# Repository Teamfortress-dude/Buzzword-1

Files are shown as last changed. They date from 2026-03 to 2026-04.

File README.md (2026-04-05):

# Buzzword-1 (NOT UPDATED, WILL UPDATE ONCE PROJECT IS FINISHED)

**What is it?**
-
The first model rocket I have ever made. It is a model rocket capable of reaching a max altitude of 400+ meters. It uses a custom G112 motor designed using OnShape and other simulation softwares and uses KNSB as propellant. It uses a CO2 ejection system. My goal with this project is to popularize model rocketry in Indonesia because currently, model rocketry is almost non-existant.

**How it roughly works**
-
1. Cook KNSB rocket propellant and cast it into PET-CF molds.
2. Create liner out of kraft paper and load in the grains each with a 2mm kraft paper separator in between each grain.
3. Load into tail end section of rocket and secure using fastening plate.
4. Set spring in CO2 piercer and load cartridge (ensure servo is powered during this process).
5. Place CO2 ejector in the upper section and load the shock cord and parachute.
6. Place rocket on launch pad (ensure the launch rod is going through the launch lug).
7. Insert igniter inside motor.
8. Stand back a minimum of 15 meters.
9. Launch.

**How the firmware roughly works**
-
I'm not 100% sure how it works either as (I'm going to be completely honest) I used AI to assist me in the creation of it, but I can tell you how to use it.

Igniter: 

1. Connect to the ESP32 DevKit v1 via bluetooth.
2. Here you can send it the required commands through the serial monitor.

Ejection System:

1. Have the ESP32-C3 Super Mini connected to your laptop via USB to lock the spring in place.
2. Ensure you are connected to the igniter as the only way to arm the system is through there.
3. Everything else is completely automatic.

**Why I made it** 
-
Ever since I was 5 years old, I have always been very interested in aviation. I began learning about different aircraft at the age of 7, and it soon became a hobby of mine to study various planes. This eventually led me to playing Kerbal Space Program, where I designed various types of jet-powered aircraft. After about a month of playing (when I was around 13 years old), I tried to build my first rocket to orbit Kerbin (KSP's version of Earth). That was when I began to get fascinated with rockets. However, it wasn't until I was 15 that I started seriously learning about rocket mechanics, the history of rocketry, and large-scale rockets.

I wanted to make a small scale model rocket but I soon realised just how unpopular model rocketry is in Indonesia, with small A class motors that usually cost 1-5$ in Canada costing over 90$ here. It was here where I decided I was going to build everything from scratch, including the motor. When I was about halfway through in just motor designing, I realised just how much this project was going to cost so I retired the project early. It was only when I discovered the Blueprint program that I immediately fired up the project again.

**CAD**
-
**Buzzword-1 Rocket Body** OnShape: https://cad.onshape.com/documents/6395d56e8419870e36c364c0/w/89d10f0ab768237c661b4cfe/e/bca3e17cd6460ee306ad322d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

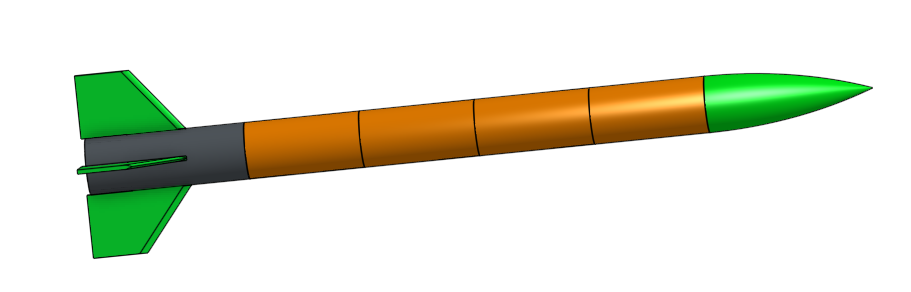
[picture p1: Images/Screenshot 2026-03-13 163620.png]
Rocket


**G112 EX Rocket Motor** OnShape: https://cad.onshape.com/documents/9d5704bc2d8bf989355a524c/w/8b6d99253b12667f572559fd/e/144e5694a96a8de6b9af8a30

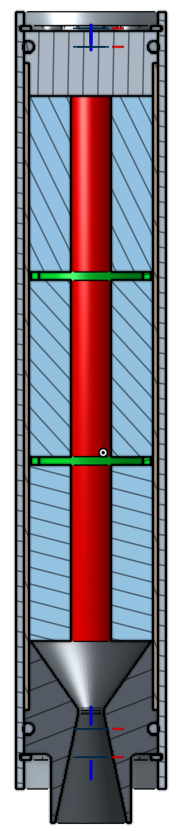
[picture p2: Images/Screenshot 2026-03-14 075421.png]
Motor


**CO2 Ejection System Frame** OnShape: https://cad.onshape.com/documents/45ce68cde51d3e3fd76b4ad7/w/09d733e07eaebf7fc37995c2/e/72d23b56d11aaa349a665c4d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

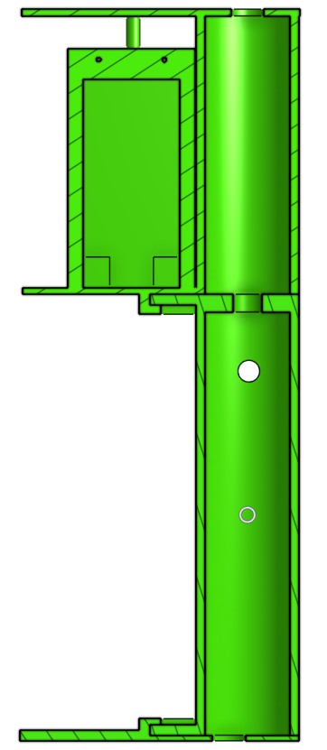
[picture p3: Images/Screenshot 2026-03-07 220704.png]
CO2


**Launch Pad Frame** OnShape: https://cad.onshape.com/documents/3f7ec817d1382ceb388e982a/w/608521341a8481e5177d8379/e/9c587c68358a26500574c930

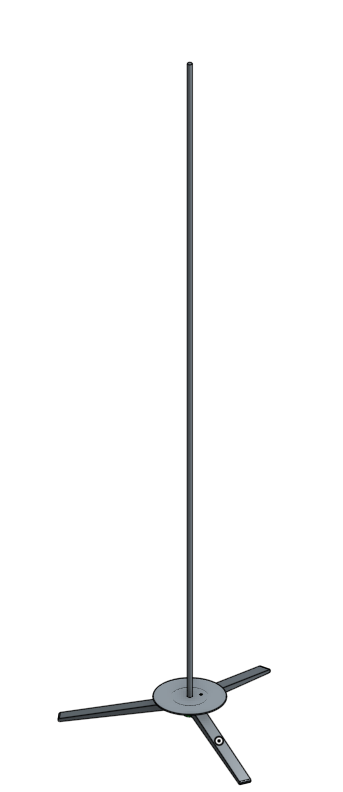
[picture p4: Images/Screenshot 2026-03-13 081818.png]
Launch


**Wireless Igniter** OnShape: https://cad.onshape.com/documents/17522f05e2172b3d15a9535d/w/4dee14af77d33351ef336225/e/4c8c179b079365a7d7b485c3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

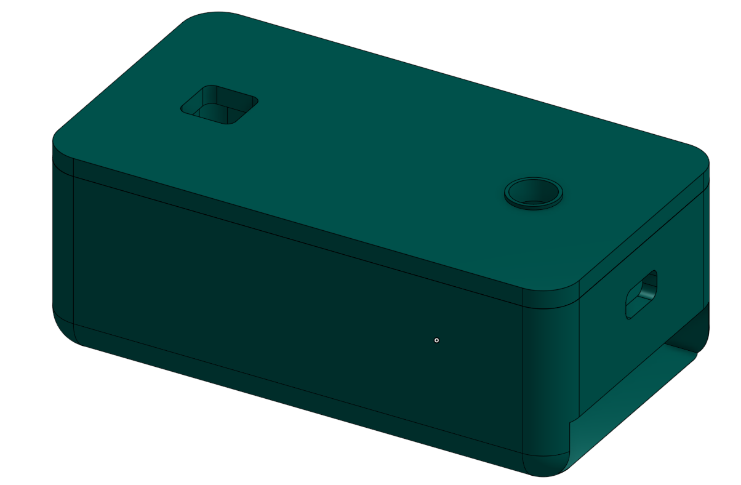
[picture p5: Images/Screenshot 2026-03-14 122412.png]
Igniter


**KNSB Mold** OnShape: https://cad.onshape.com/documents/3a6b5b3d99b7bc82c2f6d8e7/w/60bf61435858e4b373d2f9f6/e/a12e0d0e7426bf0f7a0a3a54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

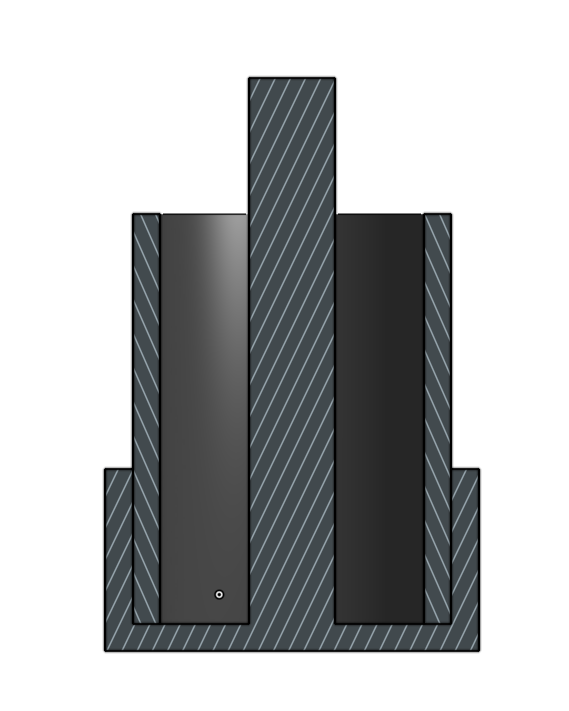
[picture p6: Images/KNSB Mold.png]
Mold


**Wiring Diagrams**
-
**CO2 Ejection System Wiring Diagram**

Ejection System_schem

**Wireless Igniter Wiring Diagram**

Igniter_schem

# Buzzword-1 Rocket BOM

(Prices converted from IDR to USD as of March 15, 2026)

Docs Link: https://docs.google.com/spreadsheets/d/1oULfb8y-ewKrFI3QsoMtwvTD6bKZGtqLrj3OP-NL9gE/edit?usp=sharing

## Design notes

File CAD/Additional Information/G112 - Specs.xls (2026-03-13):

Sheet: Intro
SRM 2023.XLS | Written by: | Richard A.Nakka
Solid Rocket Motor Performance | Version: | 2023 (for free distribution). Supercedes SRM_2014.XLS version 1.1 (2014)
 | Date: | 2023-03-23
Instructions for use: Enter required data in the blue-outlined cells (with blue text)
Note that some data cells have drop-down lists
Then click on the Solve buttons (1-3)
Introduction
Changes incorporated into SRM 2023 version
KNPSB and KNFR have been added to the choice of propellants. All propellant properties have been
tweaked based on revised two-phase flow analysis. The value of "k" is corrected to a single value. The
overall effect of these updated property values is a small reduction in predicted performance (thrust, total
impulse & specific impulse) compared to SRM_2014. Motor performance up to "V" class is now supported.
This spreadsheet was created in order to predict the performance of a Solid Rocket
Motor (SRM). Although there are many factors which make a precise prediction
of actual performance difficult, it was felt that a reasonably close approximation
to expected performance would be attainable, and be very useful for design purposes.
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

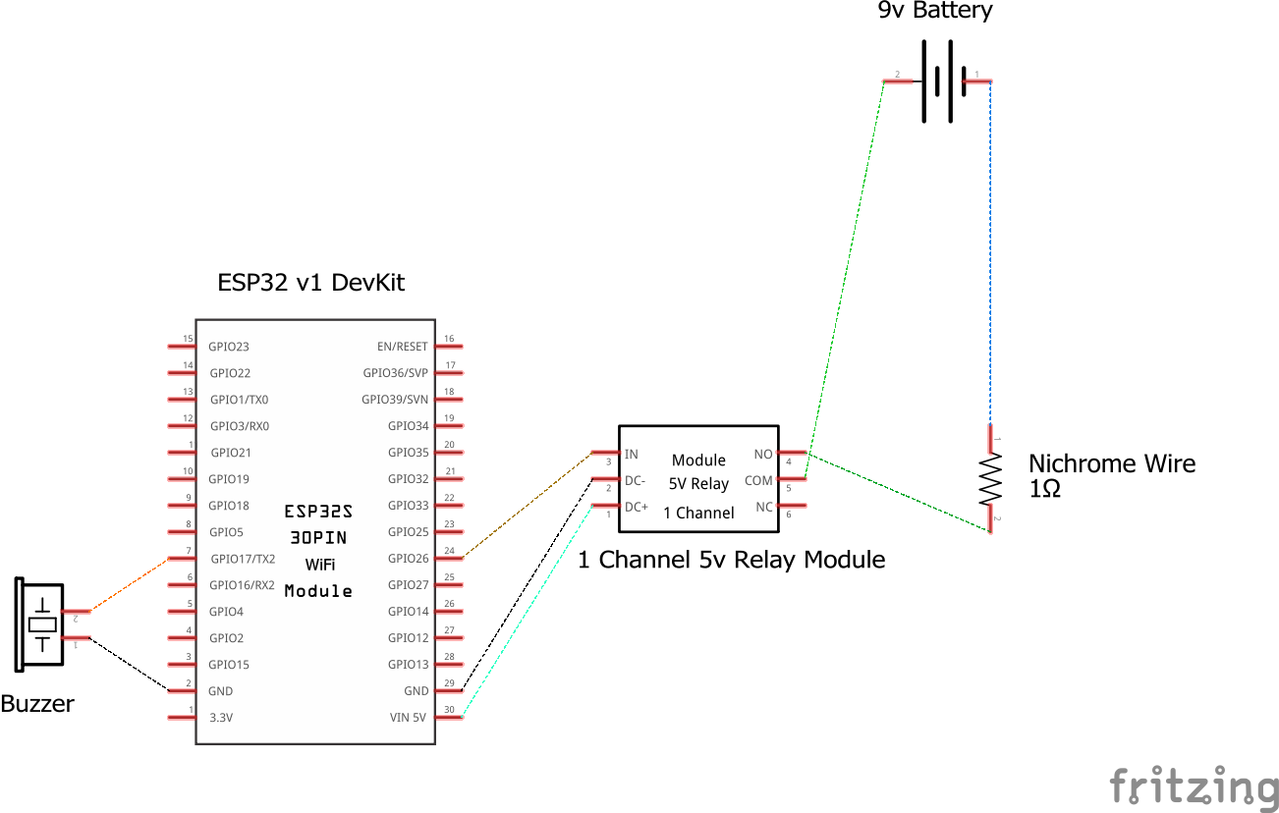
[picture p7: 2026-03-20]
Images/Igniter_schem.png

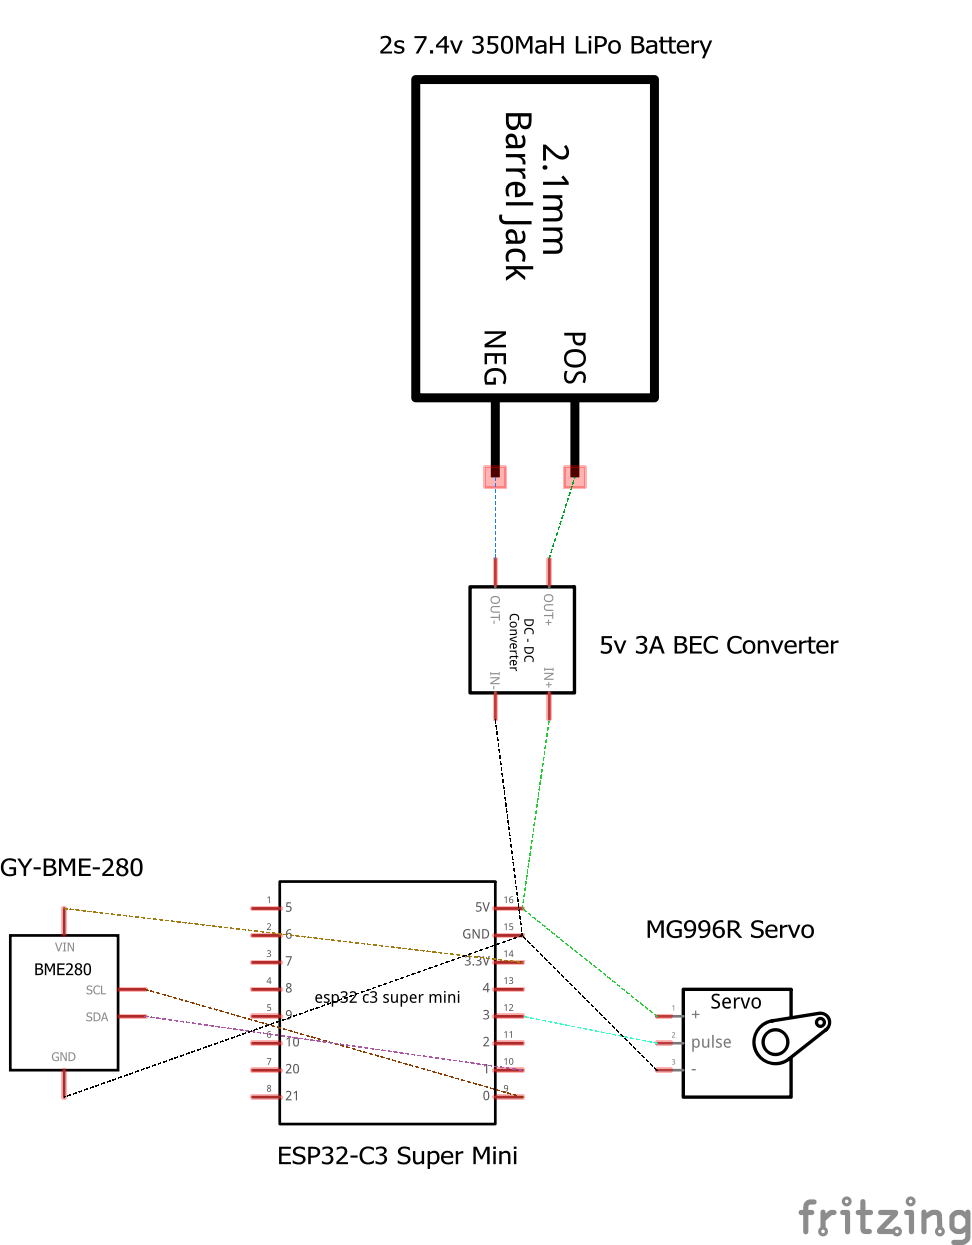
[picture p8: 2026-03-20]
Images/Ejection System_schem.png

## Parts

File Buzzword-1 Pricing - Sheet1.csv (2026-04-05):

G112 Rocket Motor
Item | Description | Quantity | Unit Price | Total Price | Links
Nozzle | CNC nozzle made of 304 stainless steel | 1 | $64.33 | $64.33 | https://drive.google.com/file/d/1FW6xyB7vkZJ01Jm_9k6G-RV7ilLzCY_d/view?usp=sharing
Casing | CNC casing made of 6061 aluminium | 1 | $70.01 | $70.01 | https://drive.google.com/file/d/1gcDKhTj_kWKR1uE6eL6LAUmwJq2hkqq-/view?usp=sharing
Bulkhead | CNC bulkhead made 6061 aluminium | 1 | $19.73 | $19.73 | https://drive.google.com/file/d/1FW6xyB7vkZJ01Jm_9k6G-RV7ilLzCY_d/view?usp=sharing
CNC Shipping 1 | Shipping cost | 1 | $17.00 | $17.00 | https://drive.google.com/file/d/1FW6xyB7vkZJ01Jm_9k6G-RV7ilLzCY_d/view?usp=sharing
CNC Shipping 2 | Secondary shipping cost due misinput on one of the items. | 1 | $1.50 | $1.50 | https://drive.google.com/file/d/1gcDKhTj_kWKR1uE6eL6LAUmwJq2hkqq-/view?usp=sharing
-120 O-ring | O-ring used for sealing gases in casing | 20 | $0.09 | $1.80 | https://www.tokopedia.com/ichibanseal/oring-as-120-25-0x2-62-id-25-0-mm-x-tebal-2-62-mm-nbr-1731112036310419029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
-121 O-ring | O-ring used for sealing gases in casing | 20 | $0.09 | $1.80 | https://www.tokopedia.com/ichibanseal/oring-as-121-26-6x2-62-id-26-6-mm-x-tebal-2-62-mm-nbr
H31 Snap ring | Snap rings used to hold nozzle and bulkhead in place | 2 | $1.88 | $3.76 | https://www.tokopedia.com/ray-fasteners/ss304-snap-ring-stainless-h31-internal-circlip-snapring-type-h-31mm
310 gsm kraft paper | Used as a thermal liner between the propellant and casing | 1 | $0.88 | $0.88 | https://www.tokopedia.com/kraftboss/kertas-kraft-liner-samson-brown-kraft-coklat-uk-a4-paket-isi-50-termurah-paper-1730794130547835917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
1kg sorbitol | Used as the fuel of the rocket motor | 1 | $6.03 | $6.03 | https://www.tokopedia.com/putrapanganprima/pemanis-sorbitol-bubuk-powder-serbuk-food-grade-100gr-250gr-500gr-1kg-1-kg-d9cf3
1kg potassium nitrate | Used as the oxidiser of the rocket motor | 1 | $3.25 | $3.25 | https://www.tokopedia.com/cocoingid/pupuk-potassium-nitrate-kno3-kingenta-repack-1-kg-80056
1 kg iron oxide | Used as a catalyst in the propellant | 1 | $2.08 | $2.08 | https://www.tokopedia.com/niochemical/iron-oxide-red-merah-1kg-1731250527442601696
Wood glue | Used to make the liner, motor mount, and grain inhibitor | 1 | $2.07 | $2.07 | https://www.tokopedia.com/aqualuxeid/aqualuxe-woodglue-lem-kayu-pvac-1kg-putih-super-kuat-cepat-kering-untuk-plamir-tembok-kertas-waterproof-dan-invisible-172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
PET-CF Filament | Used to make KNSB molds and for any high heat resistant parts | 1 | $24.75 | $24.75 | https://www.tokopedia.com/indocart/3d-printer-filament-polymaker-fiberon-pet-cf17-carbon-fiber-reinforced-pet-filament-1-75mm-500gr-1731307743431722527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
200 gsm kraft paper | Used as a grain inhibitor | 1 | $0.53 | $0.53 | https://www.tokopedia.com/kraftboss/kertas-kraft-liner-samson-brown-kraft-coklat-uk-a4-paket-isi-50-termurah-paper-1730794130547704845
Silicone grease | Used to seal the o-ring | 2 | $0.56 | $1.12 | https://www.tokopedia.com/alesya-market-store/anoso-pelumas-o-ring-grade-silicon-grease-lubricant-10g-sgl6502
 |  |  | Total Cost: | $220.64
CO2 Recovery System
Item | Description | Quantity | Unit Price | Total Price | Links
CO2 Cartridges | Used as the rapid expanding gas | 2 | $2.77 | $5.54 | https://www.tokopedia.com/esgtactical/co2-pompa-sepeda-usa-gold-gamo-original-1-kotak-isi-5pcs-12gr-1734388919894246627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
ESP32-C3 Super Mini | The microcontroller used to activate a servo at a specific altitude | 1 | $2.96 | $2.96 | https://www.tokopedia.com/ichibot/esp32-c3-supermini-development-board-dengan-wifi-dan-bluetooth-built-in-4m-flash-memory-esp32-belum-tersolder
GY-BMP-280 | A barometer module use as an altimeter for the ESP32 | 1 | $0.66 | $0.66 | https://www.tokopedia.com/solarperfect/gy-bmp280-3-3-high-precision-atmospheric-pressure-sensor-module-gy-280
24 AWG Silicone Wire | Used as the connectors between the 5V BEC and ESP32 and MG996R servo | 1 | $0.12 | $0.12 | https://www.tokopedia.com/dielectronics/24-awg-high-quality-silicone-wire-cable-kabel-silikon-serabut-putih-biru
28 AWG Wire | Used as the connector between the ESP32 and GY-BMP-280 | 1 | $0.12 | $0.12 | https://www.tokopedia.com/cncstorebandung/kabel-serabut-awg-28-awg28-high-quality-hitam
5V 3A BEC Converter | A converter between the 7.6v 2S LiPo battery and components | 1 | $1.90 | $1.90 | https://www.tokopedia.com/alladinshop/bluesky-3a-5v-ubec-bec-vdc-dc-converter-step-down-module-mini-fpv
350 MaH 2S LiPo Battery | Used as the main power source for on board avionics | 1 | $4.24 | $4.24 | https://www.tokopedia.com/justshopit/cnhl-lihv-ministar-hv-350mah-7-6v-2s-70c-lipo-battery-xt30
XT30 Plug connector | Allows the battery to plug into the BEC converter | 1 | $0.53 | $0.53 | https://www.tokopedia.com/justshopit/amass-xt30-xt30u-plug-connector-female-male-lipo-battery-for-rc-fpv-drone-1729895395040659171
Heat shrink wire covers set | Allow for cleaner and sturdier connections | 1 | $0.65 | $0.65 | https://www.tokopedia.com/skf88/heat-shrink-kabel-164-530pcs-isolasi-bakar-tube-selang-bakar-bahan-polyolefin-warna-warni-1732990049052886837
 |  |  | Total Cost: | $16.72
Rocket Body Construction
Item | Description | Quantity | Unit Price | Total Price | Links
Parachute | Will be used as the recovery system | 1 | $1.72 | $1.72 | https://www.tokopedia.com/penny-y/2pcs-mainan-parasut-anak-mainan-anak-terjun-payung-terjun-payung-mainan-payung-terjun-merah-2pcs-6cad4
Sandpaper | Used to smooth out the rocket body | 2 | $0.51 | $1.02 | https://www.tokopedia.com/ud-33/paket-amplas-auto-kinclong-duco-lembar-320-2000-3000-1dfe8?t_id=1774713139184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
4mm Paracord per meter | Used as a shock cord connecting the nose to the rocket body during recovery | 4 | $0.71 | $2.84 | https://www.tokopedia.com/acckingdom47/genuine-tali-paracord-550-4mm-asli-premium-kuat-motif-multicolor-uv-resistant-anti-pudar-survival-cord-serbaguna-gunung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
 |  |  | Total Cost: | $5.58
Launchpad and Igniter
Item | Description | Quantity | Unit Price | Total Price | Links
15 cm Stainless steel disk | Used for redicrecting the hot exhaust gas during launch | 1 | $1.48 | $1.48 | https://www.tokopedia.com/ajm175/plat-bulat-stainless-1-2-mm-uk-5-20-cm-1731311695462827268
155cm Stainless steel rod | Used as the launch rod to guide the rocket during takeoff | 1 | $7.75 | $7.75 | https://www.tokopedia.com/rajawali3d/smooth-rod-stainless-steel-304-10mm-per-cm-linear-shaft-rail
ESP32 DevKit v1 | Used for wireless ignition | 1 | $5.08 | $5.08 | https://www.tokopedia.com/cncstorebandung/esp32-esp-32s-doit-cp2102-type-c-38-pin-board-wifi-bluetooth-iot-dual-core-proyek-elektronik-1731127910335219262
9v Battery | Used to power ignition | 4 | $0.26 | $1.04 | https://www.tokopedia.com/kastiltermurah/baterai-battery-batre-batere-kotak-9v-9volt-9-volt-v-batu-huadao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
1 Channel 5v relay | Used to initiate the 9v battery to heat nichrome | 1 | $0.98 | $0.98 | https://www.tokopedia.com/cncstorebandung/relay-1-channel-relay-5v-with-optocoupler-high-quality-1733708580343678526
Nichrome wire | Used as the heating element to ignite rocket motor | 2 | $0.18 | $0.36 | https://www.tokopedia.com/pcmelektronikpusat/kawat-nikelin-nikel-pemanas-0-2mm-meteran-nichrome-wire-0-2mm-mm-bulat
 |  |  | Total Cost: | $16.69
Total Overall Cost: | $273.28 |  | Avg. Shipping Cost: | $13.65
Note: All these costs are converted from Indonesian IDR to USD as of March 15, 2026
Note: Shipping here in Indonesia is mostly free and uniform which is why I added the average delivery cost except for the CNC

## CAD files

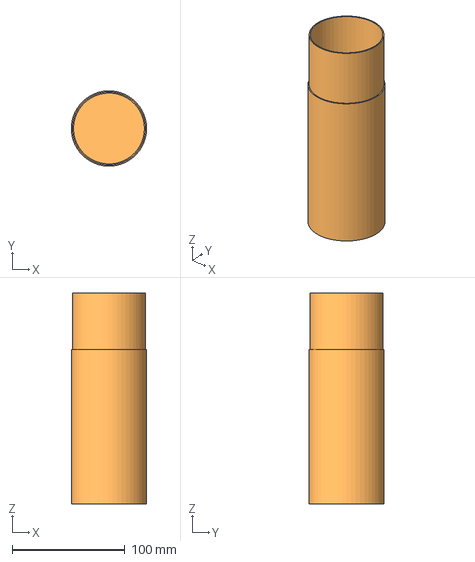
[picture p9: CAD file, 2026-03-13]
CAD/Buzzword-1 Body/Middle Section 2.step
66.9 x 67.0 x 187.5 mm

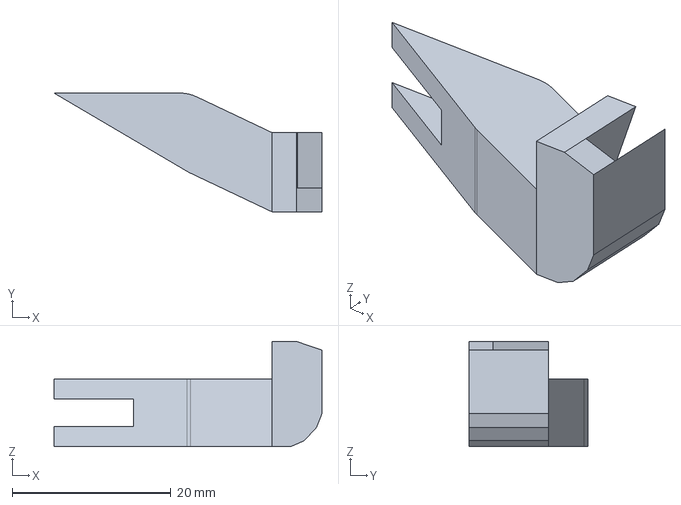
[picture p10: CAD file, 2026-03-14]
CAD/CO2 Piercer/Handle.step
33.8 x 15.0 x 13.2 mm

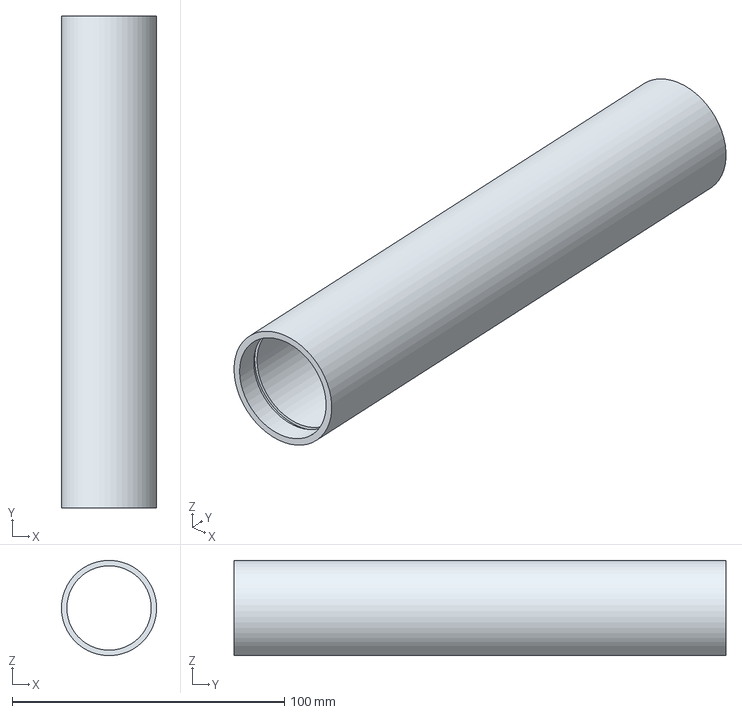
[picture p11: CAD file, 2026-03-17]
CAD/G112 EX Rocket Motor/Casing - L1.step
35.0 x 180.8 x 35.0 mm

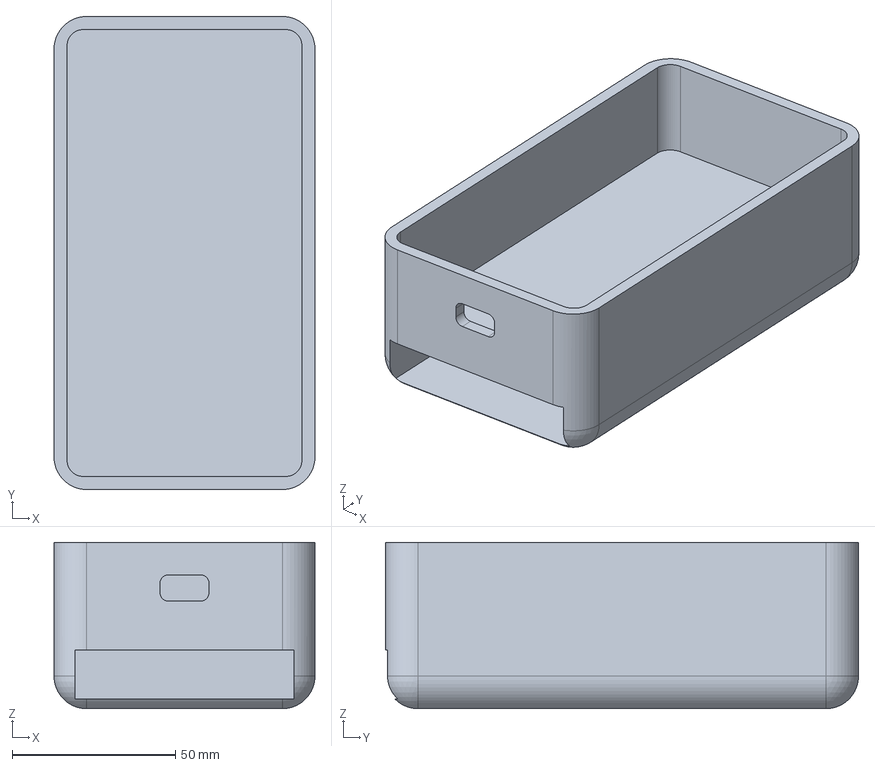
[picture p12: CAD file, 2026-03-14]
CAD/Igniter Box/Box.step
80.0 x 145.0 x 51.0 mm

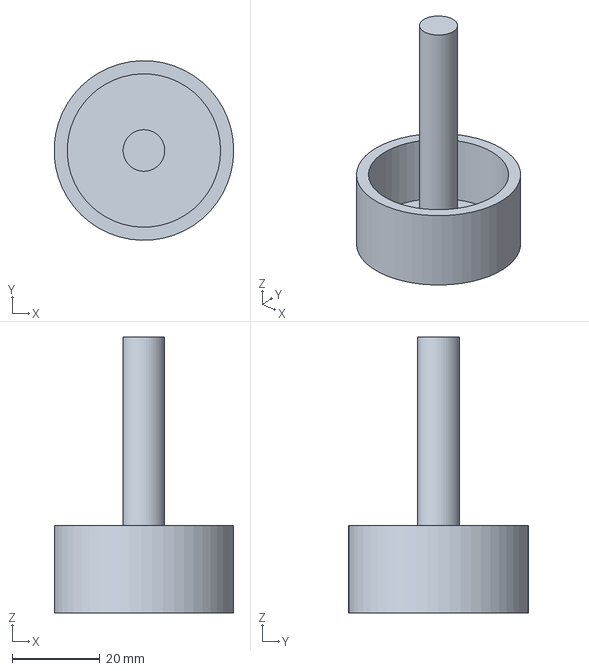
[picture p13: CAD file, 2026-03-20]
CAD/KNSB Mold/Coring Tool.step
41.0 x 41.0 x 63.0 mm

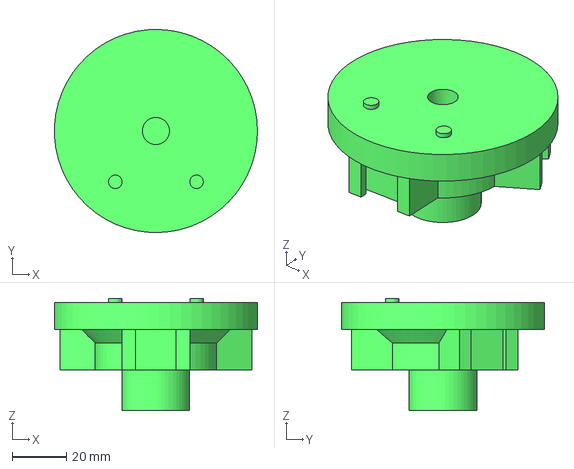
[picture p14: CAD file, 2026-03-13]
CAD/Launch Pad/Launch Pad.step
74.9 x 75.0 x 41.5 mm

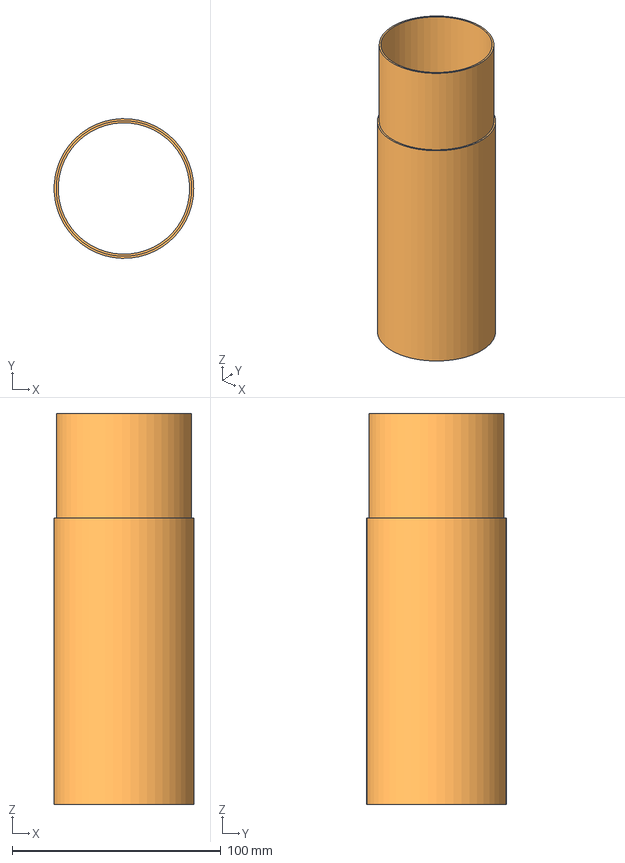
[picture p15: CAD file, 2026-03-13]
CAD/Buzzword-1 Body/Middle Section 1.step
66.9 x 67.0 x 187.5 mm

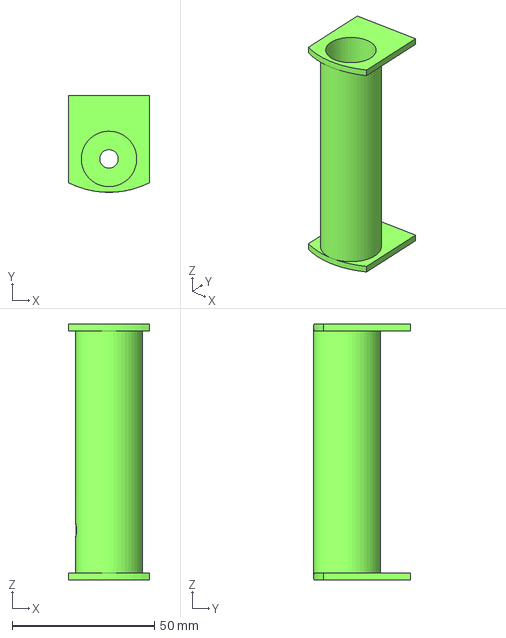
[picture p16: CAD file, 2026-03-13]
CAD/CO2 Piercer/CO2 Tube.step
28.5 x 34.0 x 90.0 mm

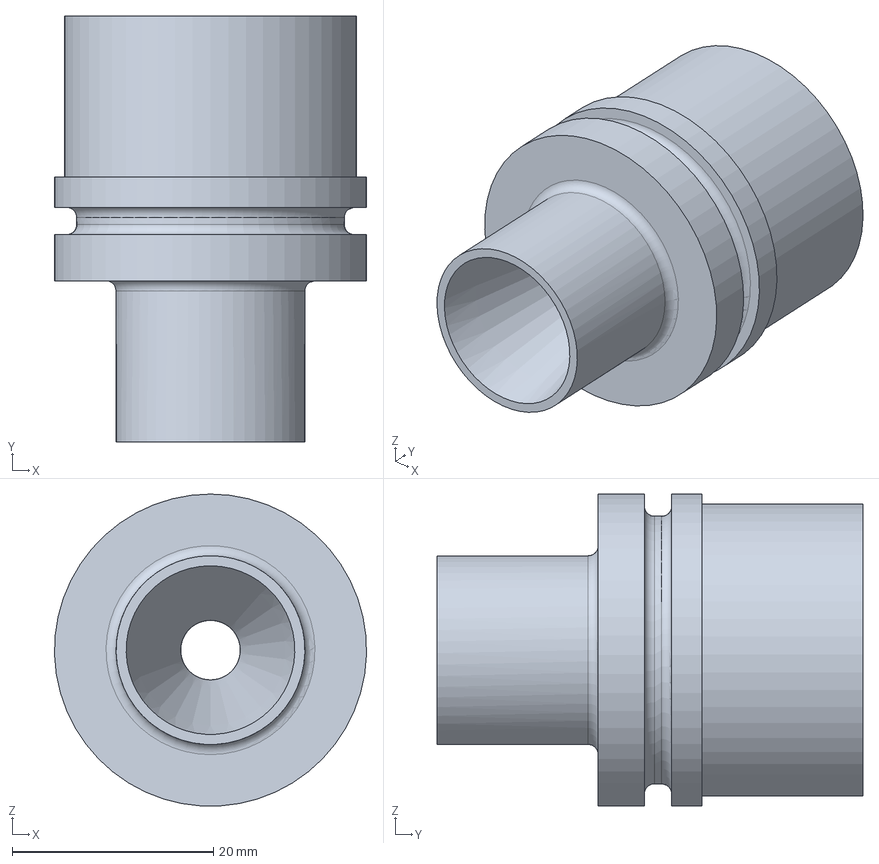
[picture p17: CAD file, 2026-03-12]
CAD/G112 EX Rocket Motor/Nozzle - L1.step
31.0 x 42.3 x 31.0 mm

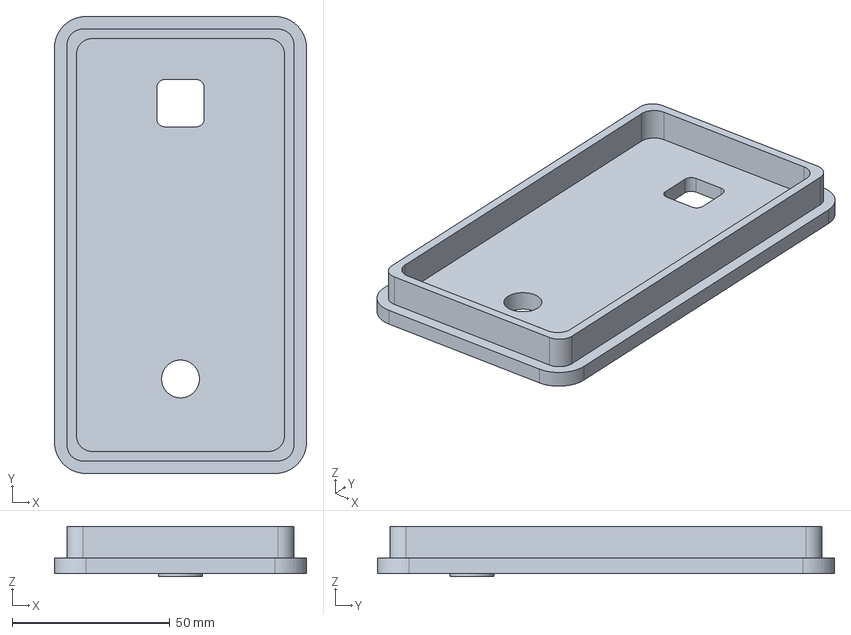
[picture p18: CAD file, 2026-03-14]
CAD/Igniter Box/Lid .step
80.0 x 145.0 x 16.0 mm

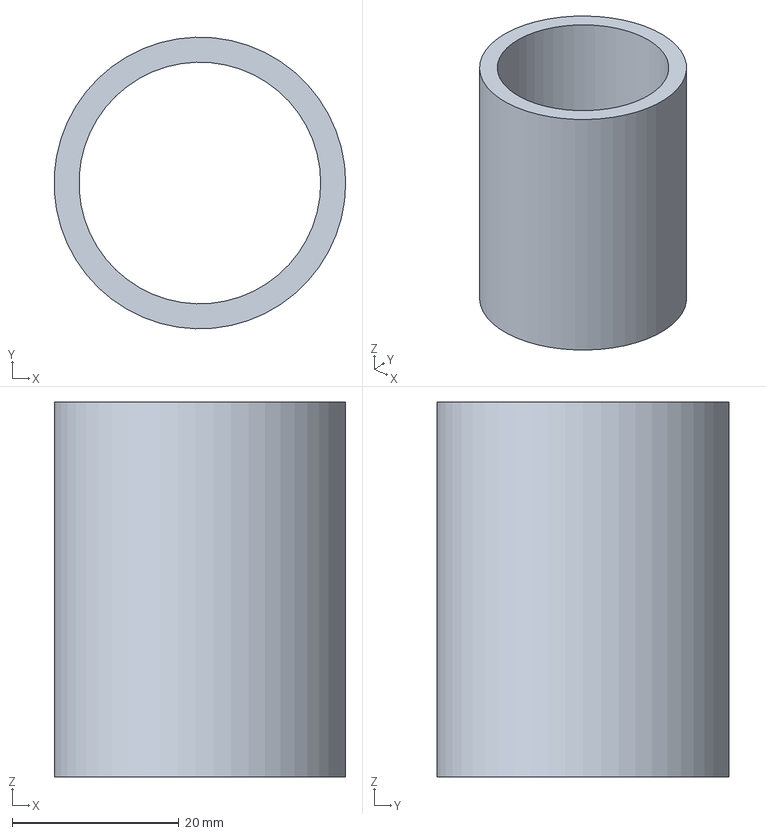
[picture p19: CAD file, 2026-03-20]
CAD/KNSB Mold/Mold.step
35.0 x 35.0 x 45.0 mm

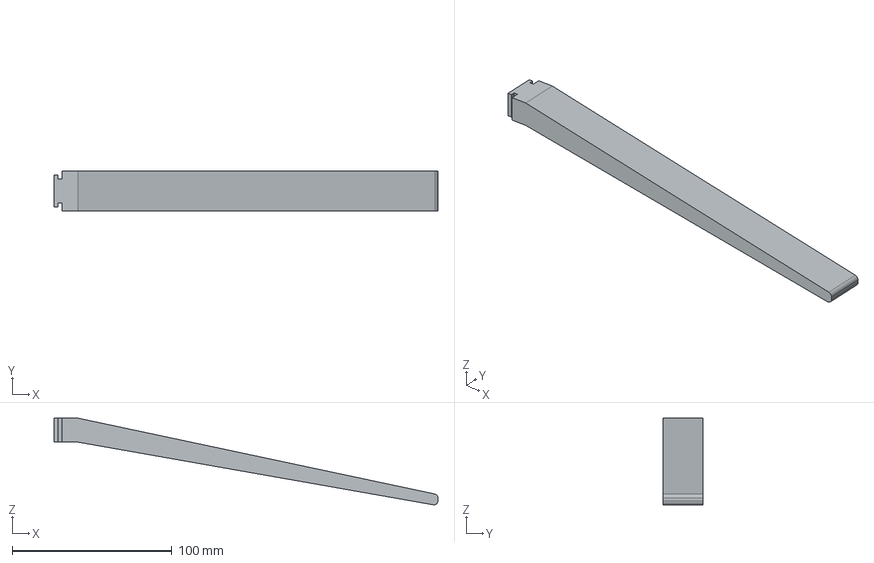
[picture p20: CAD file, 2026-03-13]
CAD/Launch Pad/Leg.step
240.0 x 25.0 x 54.2 mm

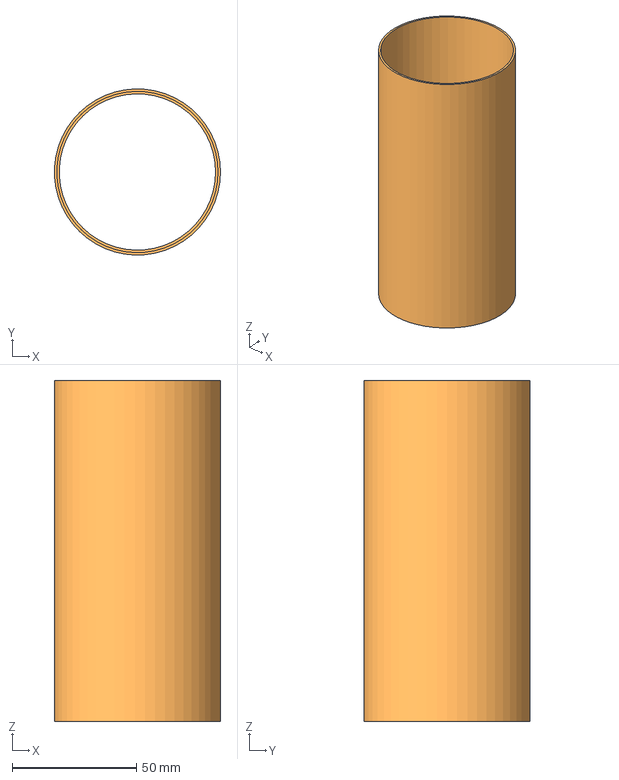
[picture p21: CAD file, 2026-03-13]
CAD/Buzzword-1 Body/Lower Section.step
66.9 x 67.0 x 137.5 mm

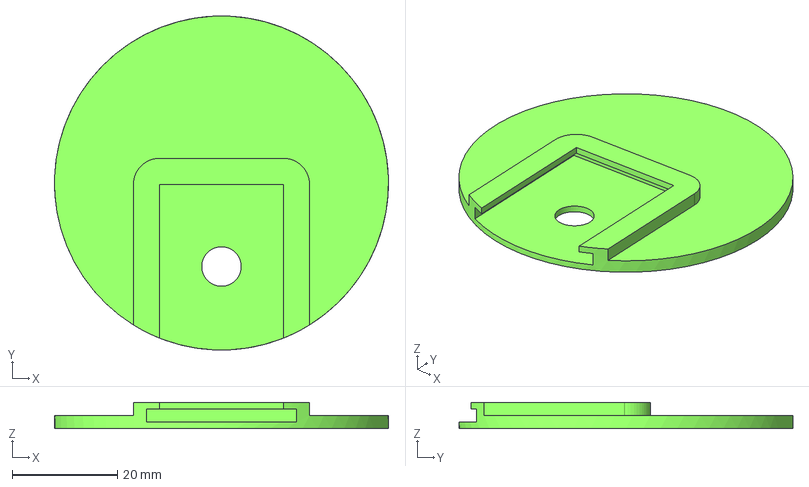
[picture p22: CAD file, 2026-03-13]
CAD/CO2 Piercer/Lid.step
63.5 x 63.5 x 5.00 mm

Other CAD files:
CAD/G112 EX Rocket Motor/Bulkhead - L1.step
CAD/Buzzword-1 Body/Upper Section.step
CAD/CO2 Piercer/Mount.step
CAD/Buzzword-1 Body/Motor Section.step
CAD/Buzzword-1 Body/Fins.step
CAD/Buzzword-1 Body/Nose Cone.step
CAD/CO2 Piercer/Casing.step

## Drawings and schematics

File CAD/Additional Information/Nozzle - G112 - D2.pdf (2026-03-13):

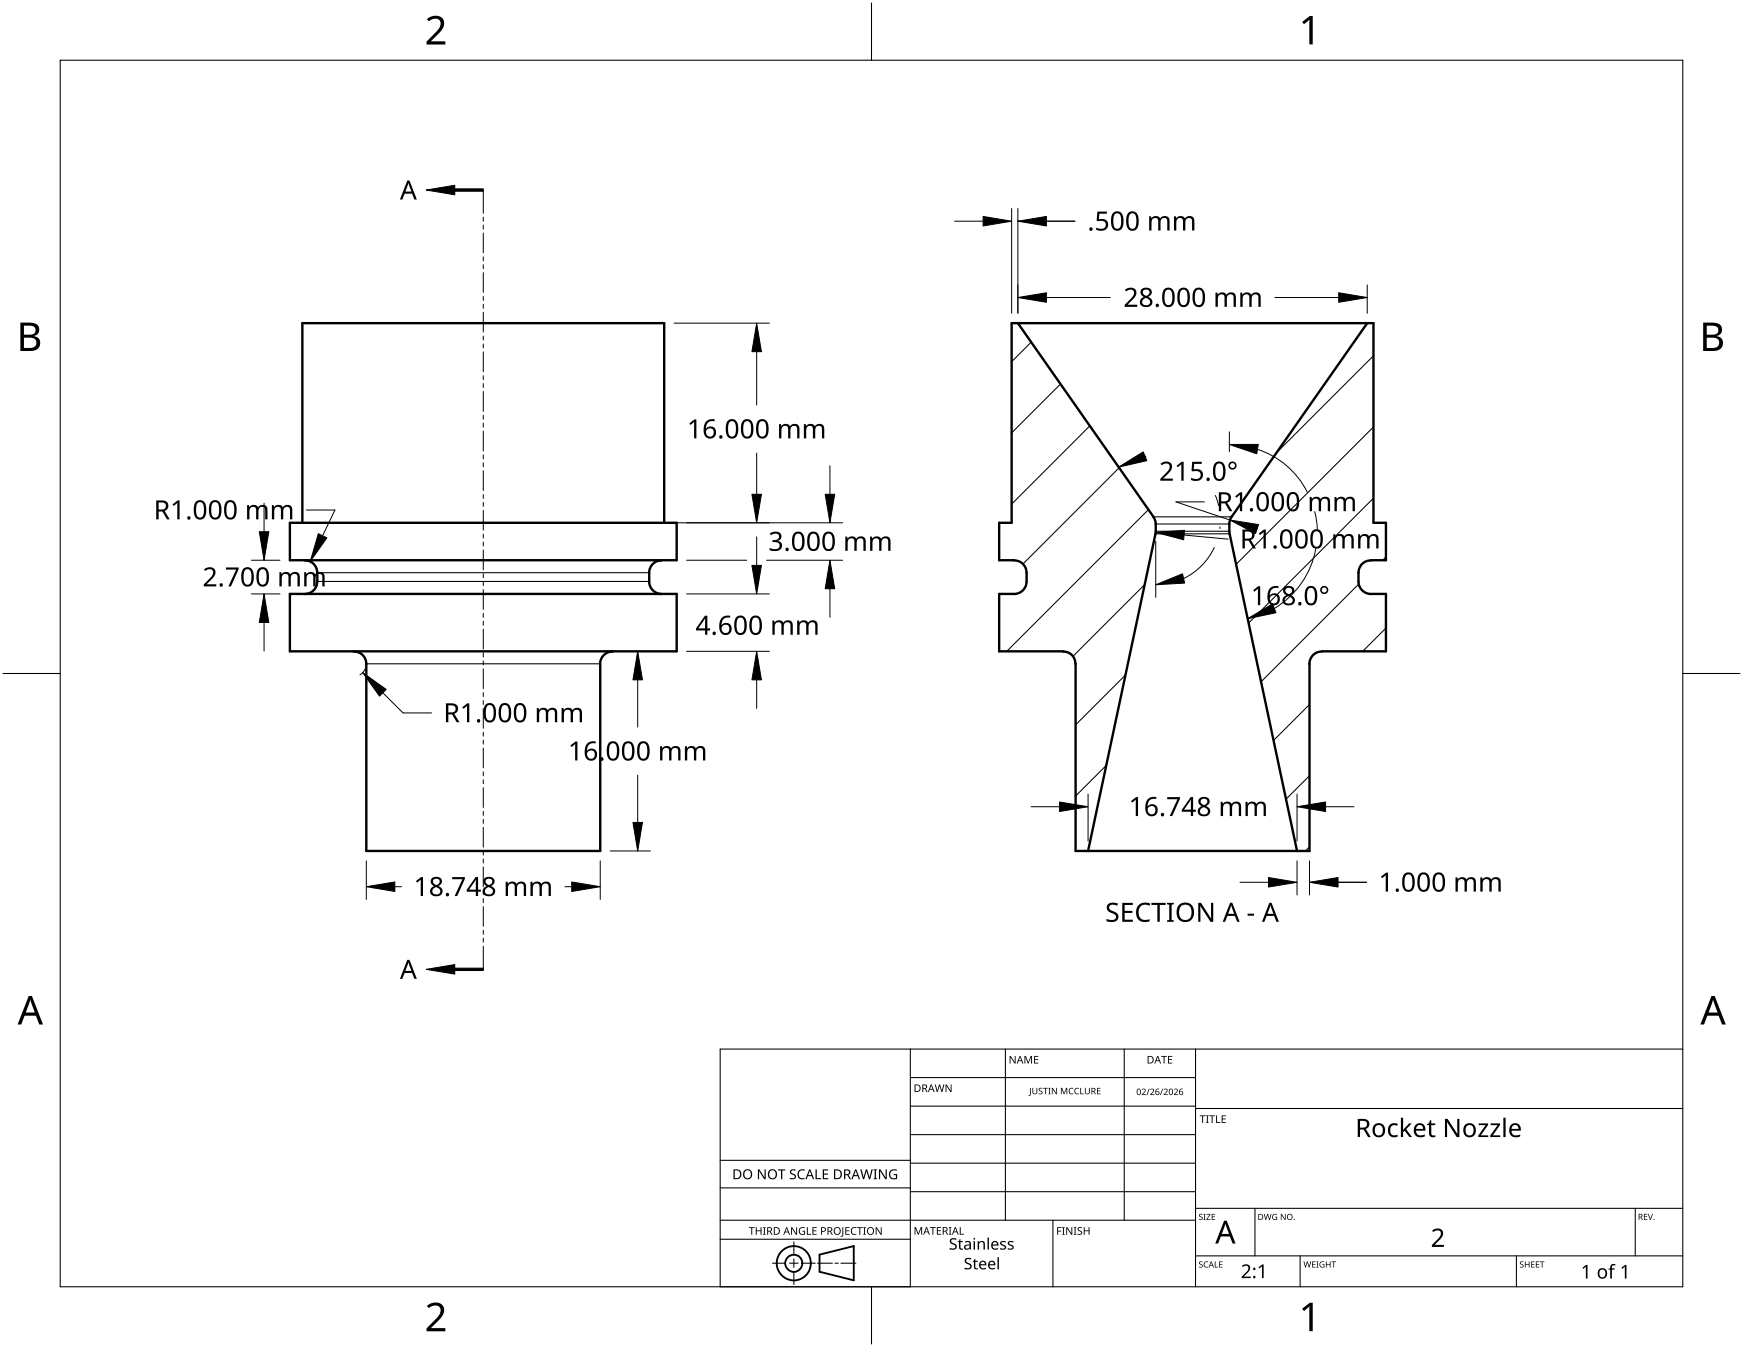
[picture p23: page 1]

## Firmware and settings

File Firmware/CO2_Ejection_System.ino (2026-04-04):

// ============================================================
//  CO2 EJECTION SYSTEM — FLIGHT CODE
//  ESP32-C3 Super Mini
//
//  FIXES FROM ORIGINAL:
//    1. Changed Servo.h -> ESP32Servo.h (compatible with ESP32 core 3.x)
//    2. Corrected servo angles: ARMED = 90deg, EJECT = 0deg
//    3. Added 8-second timed gate — altitude must hold for full
//       gate duration before servo fires
//    4. Ground pressure captured BEFORE waiting for TAKEOFF signal
//       so baseline is always taken at ground level
//    5. Fixed missing closing brace on loop()
//    6. Target altitude corrected to 450m
// ============================================================

#include <Wire.h>
#include <Adafruit_BMP280.h>
#include <ESP32Servo.h>
#include <esp_now.h>
#include <WiFi.h>

// ── Pin definitions ──────────────────────────────────────────
#define SDA_PIN    8
#define SCL_PIN    9
#define SERVO_PIN  10

// ── Configuration ────────────────────────────────────────────
const float TARGET_ALTITUDE    = 450.0;   // metres — ejection altitude
const int   ARMED_ANGLE        = 90;      // servo position while armed
const int   EJECT_ANGLE        = 0;       // servo position on ejection
const unsigned long GATE_MS    = 8000;    // timed gate — ms above altitude before fire

// ── Objects ──────────────────────────────────────────────────
Adafruit_BMP280 bmp;
Servo ejectionServo;

typedef struct message_struct {
  char message[32];
} message_struct;

message_struct incomingData;

// ── State ────────────────────────────────────────────────────
float groundPressure     = 0.0;
bool  armed              = false;
bool  ejected            = false;
bool  takeoffReceived    = false;
bool  gateOpen           = false;
unsigned long gateStart  = 0;

// ── ESP-NOW callback ─────────────────────────────────────────
void onDataRecv(const esp_now_recv_info_t *recv_info, const uint8_t *data, int len) {
  memcpy(&incomingData, data, sizeof(incomingData));
  if (strcmp(incomingData.message, "TAKEOFF") == 0 && !takeoffReceived) {
    takeoffReceived = true;
    Serial.println("TAKEOFF SIGNAL RECEIVED - ARMING SYSTEM!");
  }
}

// ─────────────────────────────────────────────────────────────
void setup() {
  Serial.begin(115200);
  delay(100);

  // ── Print MAC address ────────────────────────────────────
  WiFi.mode(WIFI_STA);
  Serial.print("ESP32-C3 MAC Address: ");
  Serial.println(WiFi.macAddress());

  // ── Servo init ───────────────────────────────────────────
  ejectionServo.attach(SERVO_PIN);
  ejectionServo.write(ARMED_ANGLE);
  Serial.print("Servo initialised at ");
  Serial.print(ARMED_ANGLE);
  Serial.println("deg (armed)");

  // ── BMP280 init ──────────────────────────────────────────
  Wire.begin(SDA_PIN, SCL_PIN);
  if (!bmp.begin(0x76)) {
    Serial.println("BMP280 not found! Check wiring.");
    while (1) delay(10);
  }
  bmp.setSampling(Adafruit_BMP280::MODE_NORMAL,
                  Adafruit_BMP280::SAMPLING_X2,
                  Adafruit_BMP280::SAMPLING_X16,
                  Adafruit_BMP280::FILTER_X16,
                  Adafruit_BMP280::STANDBY_MS_500);

  // ── Capture ground pressure BEFORE waiting for signal ────
  // Average 10 readings for a stable baseline
  Serial.println("Capturing ground pressure baseline...");
  float pressureSum = 0;
  for (int i = 0; i < 10; i++) {
    pressureSum += bmp.readPressure() / 100.0F;
    delay(100);
  }
  groundPressure = pressureSum / 10.0;
  Serial.print("Ground pressure locked: ");
  Serial.print(groundPressure, 2);
  Serial.println(" hPa");

  // ── ESP-NOW init ─────────────────────────────────────────
  if (esp_now_init() != ESP_OK) {
    Serial.println("ESP-NOW init failed!");
    while (1) delay(10);
  }
  esp_now_register_recv_cb(onDataRecv);
  Serial.println("ESP-NOW ready - waiting for TAKEOFF signal...");

  // ── Wait for TAKEOFF signal from igniter board ───────────
  while (!takeoffReceived) {
    Serial.println("Waiting for takeoff signal...");
    delay(500);
  }

  armed = true;

  Serial.println("=== SYSTEM ARMED AT LAUNCH ===");
  Serial.print("Target ejection altitude : ");
  Serial.print(TARGET_ALTITUDE);
  Serial.println(" m");
  Serial.print("Timed gate               : ");
  Serial.print(GATE_MS / 1000);
  Serial.println(" s");
}

// ─────────────────────────────────────────────────────────────
void loop() {
  if (!armed || ejected) {
    delay(100);
    return;
  }

  float altitude = bmp.readAltitude(groundPressure);

  Serial.print("Altitude: ");
  Serial.print(altitude, 1);
  Serial.print(" m");

  // ── Altitude threshold check ──────────────────────────────
  if (altitude >= TARGET_ALTITUDE) {

    if (!gateOpen) {
      // First time crossing threshold — open the gate
      gateOpen  = true;
      gateStart = millis();
      Serial.print("  << GATE OPENED >>");
    }

    unsigned long elapsed   = millis() - gateStart;
    unsigned long remaining = (elapsed >= GATE_MS) ? 0 : (GATE_MS - elapsed);
    Serial.print("  Gate: ");
    Serial.print(remaining / 1000.0, 1);
    Serial.print("s remaining");

    // ── Fire if gate has passed ───────────────────────────
    if (elapsed >= GATE_MS) {
      Serial.println();
      Serial.println("*** EJECTION TRIGGERED — GATE PASSED ***");
      ejectionServo.write(EJECT_ANGLE);
      ejected = true;
      Serial.print("Servo moved to ");
      Serial.print(EJECT_ANGLE);
      Serial.println("deg — Ejection complete.");
      return;
    }

  } else {
    // Dropped back below threshold — reset gate
    if (gateOpen) {
      Serial.print("  << GATE RESET — altitude lost >>");
      gateOpen = false;
      gateStart = 0;
    }
  }

  Serial.println();
  delay(100);   // 10 Hz loop
}

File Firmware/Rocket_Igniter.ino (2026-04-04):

// ============================================================
//  ROCKET IGNITER — FLIGHT CODE
//  Send TAKEOFF via ESP-NOW to ejection board, then fire relay
//
//  FIXES FROM ORIGINAL:
//    1. sendTakeoff() is now called BEFORE digitalWrite(RELAY_PIN, HIGH)
//       so the ejection board locks its ground pressure baseline
//       before the rocket moves
//    2. Small delay added after TAKEOFF signal to give ejection
//       board time to process before ignition
//    3. Both launch paths (countdown + instant) updated consistently
// ============================================================

#include <BluetoothSerial.h>
#include <esp_now.h>
#include <WiFi.h>

// ── Configuration ─────────────────────────────────────────────
const int RELAY_PIN     = 5;   // Relay for nichrome wire
const int BUZZER_PIN    = 4;   // Passive buzzer
const int LAUNCH_BUTTON = 0;   // Boot button

const char* bluetoothName = "RocketIgniter";

// !! IMPORTANT: Replace with the actual MAC address of your
//    ejection board ESP32-C3. Flash the ejection code first,
//    read the MAC from Serial Monitor on boot, then fill in here.
uint8_t c3MacAddress[] = {0xXX, 0xXX, 0xXX, 0xXX, 0xXX, 0xXX};

// ── Objects & state ───────────────────────────────────────────
BluetoothSerial SerialBT;

typedef struct message_struct {
  char message[32];
} message_struct;

message_struct outgoingData;

bool countdownActive  = false;
bool launchTriggered  = false;
unsigned long countdownStart = 0;

// ── Send TAKEOFF signal via ESP-NOW ───────────────────────────
void sendTakeoff() {
  strcpy(outgoingData.message, "TAKEOFF");
  esp_now_send(c3MacAddress, (uint8_t*)&outgoingData, sizeof(outgoingData));
  Serial.println("TAKEOFF sent to ejection board");
  SerialBT.println("TAKEOFF sent to ejection board");
}

// ── Fire sequence: signal first, THEN ignite ─────────────────
void fireIgniter() {
  // 1. Tell ejection board we are launching (locks ground pressure)
  sendTakeoff();
  delay(200);   // brief pause — gives C3 time to receive and arm

  // 2. Fire the nichrome relay
  Serial.println("Firing igniter...");
  SerialBT.println("Firing igniter...");
  digitalWrite(RELAY_PIN, HIGH);
  delay(1000);
  digitalWrite(RELAY_PIN, LOW);

  launchTriggered = true;
  Serial.println("Igniter fired. Launch complete.");
  SerialBT.println("Igniter fired. Launch complete.");
}

// ─────────────────────────────────────────────────────────────
void setup() {
  Serial.begin(115200);
  delay(100);

  pinMode(RELAY_PIN, OUTPUT);
  digitalWrite(RELAY_PIN, LOW);
  pinMode(BUZZER_PIN, OUTPUT);
  noTone(BUZZER_PIN);
  pinMode(LAUNCH_BUTTON, INPUT_PULLUP);

  // Bluetooth
  SerialBT.begin(bluetoothName);
  Serial.println("\nBluetooth started! Device: " + String(bluetoothName));
  Serial.println("Commands: START  |  CANCEL");

  // ESP-NOW
  WiFi.mode(WIFI_STA);
  Serial.print("Igniter MAC Address: ");
  Serial.println(WiFi.macAddress());

  if (esp_now_init() != ESP_OK) {
    Serial.println("ESP-NOW init failed!");
    while (1) delay(10);
  }

  esp_now_peer_info_t peerInfo = {};
  memcpy(peerInfo.peer_addr, c3MacAddress, 6);
  esp_now_add_peer(&peerInfo);

  Serial.println("=== IGNITER READY ===");
}

// ─────────────────────────────────────────────────────────────
void loop() {

  // ── Read command from USB Serial or Bluetooth ─────────────
  String cmd = "";
  if (Serial.available()) {
    cmd = Serial.readStringUntil('\n');
  } else if (SerialBT.available()) {
    cmd = SerialBT.readStringUntil('\n');
  }

  if (cmd.length() > 0) {
    cmd.trim();
    cmd.toUpperCase();

    if (cmd == "START" && !countdownActive && !launchTriggered) {
      countdownActive = true;
      countdownStart  = millis();
      Serial.println("10s COUNTDOWN STARTED");
      SerialBT.println("10s COUNTDOWN STARTED");
    }
    else if (cmd == "CANCEL" && countdownActive) {
      countdownActive = false;
      noTone(BUZZER_PIN);
      digitalWrite(RELAY_PIN, LOW);
      Serial.println("COUNTDOWN CANCELLED");
      SerialBT.println("COUNTDOWN CANCELLED");
    }
  }

  // ── Countdown logic ───────────────────────────────────────
  if (countdownActive) {
    unsigned long elapsed = (millis() - countdownStart) / 1000;

    if (elapsed < 10) {
      int remaining = 10 - (int)elapsed;
      Serial.print("Countdown: ");
      Serial.println(remaining);
      SerialBT.print("Countdown: ");
      SerialBT.println(remaining);

      tone(BUZZER_PIN, 1200, 300);
      delay(400);

    } else {
      // Countdown complete
      Serial.println("*** LAUNCHING ***");
      SerialBT.println("*** LAUNCHING ***");
      noTone(BUZZER_PIN);
      countdownActive = false;
      fireIgniter();
    }
  }

  // ── Physical button — instant launch ─────────────────────
  if (digitalRead(LAUNCH_BUTTON) == LOW && !launchTriggered && !countdownActive) {
    delay(50);   // debounce
    if (digitalRead(LAUNCH_BUTTON) == LOW) {
      Serial.println("*** INSTANT LAUNCH ***");
      SerialBT.println("*** INSTANT LAUNCH ***");
      fireIgniter();
    }
  }

  delay(10);
}

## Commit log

2026-03-13 Rename L1 - Specs.xls to G112 - Specs.xls
    [G112 - Specs.xls]
2026-03-13 Rename Nozzle - L1 - D2.pdf to Nozzle - G112 - D2.pdf
2026-03-14 Rename Buzzword-1 Pricing - Sheet1.csv to BOM.csv
    [BOM.csv, Buzzword-1 Pricing - Sheet1.csv]
2026-03-14 Rename Screenshot 2026-03-07 220704.png to CO2 Ejection Frame
2026-03-14 Rename Screenshot 2026-03-14 122412.png to Wireless Igniter Frame
2026-03-20 Rename Screenshot 2026-03-20 113735.png to KNSB Mold
2026-03-24 Rename Buzzword-1 Pricing - Sheet1.csv to BOM
2026-03-24 Rename CO2 Ejection Frame to CO2 Ejection Frame.png
2026-03-24 Rename KNSB Mold to KNSB Mold.png
2026-03-24 Rename Wireless Igniter Frame to Wireless Igniter Frame.png
